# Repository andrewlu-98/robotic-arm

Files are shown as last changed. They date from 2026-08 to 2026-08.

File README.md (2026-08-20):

# 6-Axis Robotic Arm (Work in Progress)

An open-source, 6-DOF robotic arm featuring a custom mixed-architecture control board. The system offloads inverse kinematics (ROS 2 / Python) from a host laptop to an onboard Raspberry Pi Pico W analyzing encoder data and generating step signals.

---

## Hardware Overview

### Mechanical
The physical structure consists of a custom 3D printed robotic arm with one meter span. Joints are driven with Nema stepper motors through gear ratios and pulleys, controlling rotation and movement of arm. Motors are to be guided through sensor inputs (limit switches, MT6701) and controlled via Nema Stepper Motors and precise gear ratios.
<p align="center">
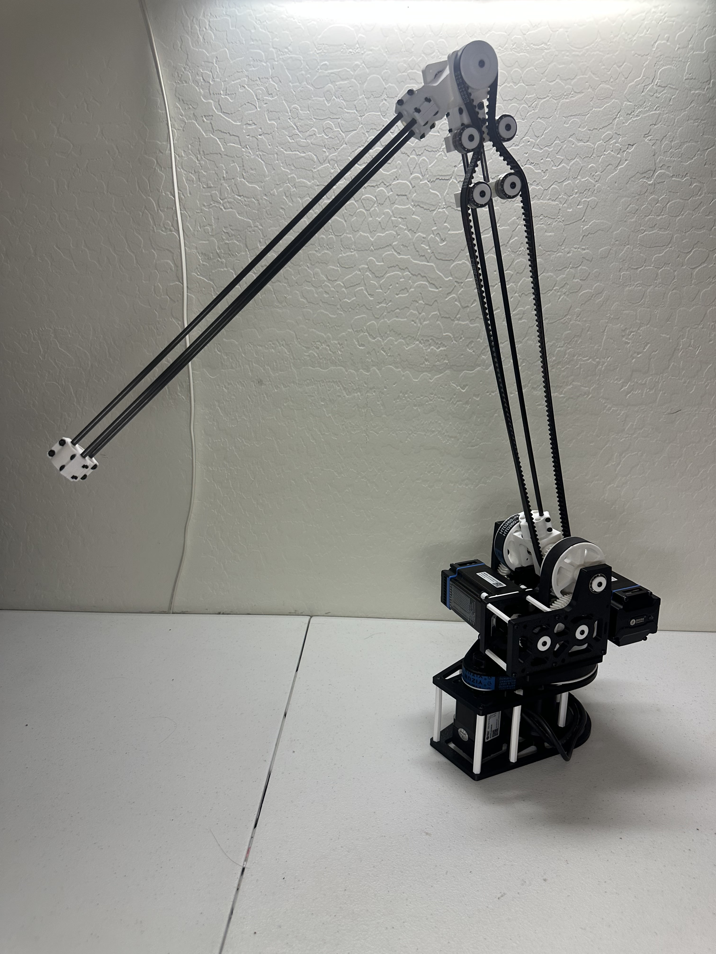
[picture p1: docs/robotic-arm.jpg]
Physical Arm Structure
  
</p>

### Electrical
Electronics consist of a power supply unit (connected to a wall outlet) sent to a PCB that actively controls the robotic arm through signals to the stepper motors and data from encoders and limit switches mounted near the stepper motors on the physical arm.
<p align="center">
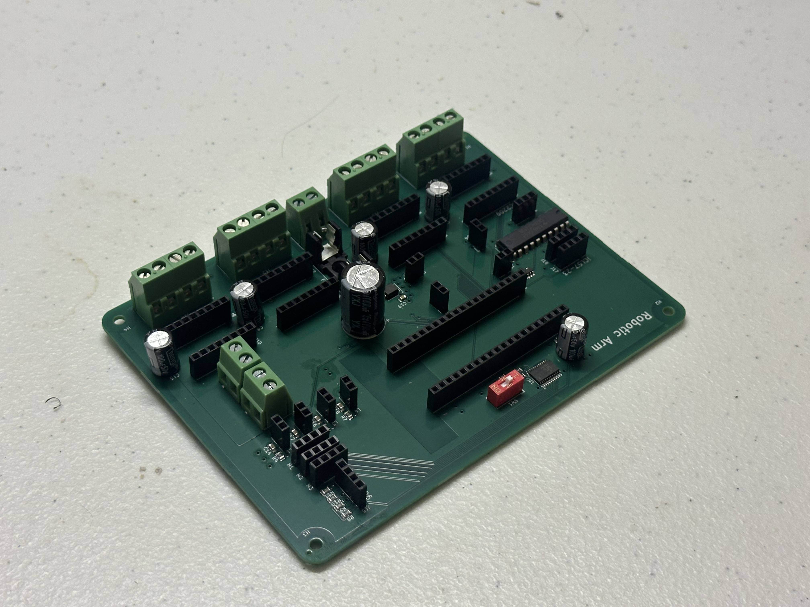
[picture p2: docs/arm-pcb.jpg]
Assembled PCB
  
</p>

The printed circuit board handles logic shifting via 74HCT245, limit switch & encoder monitoring, and I2C multiplexing. It houses pin headers for reusability of all boards in case of PCB failure. The board has thermal reliefs on 24V power pours, decoupling, and pull-up resistors for limit switch activation.
<p align="center">
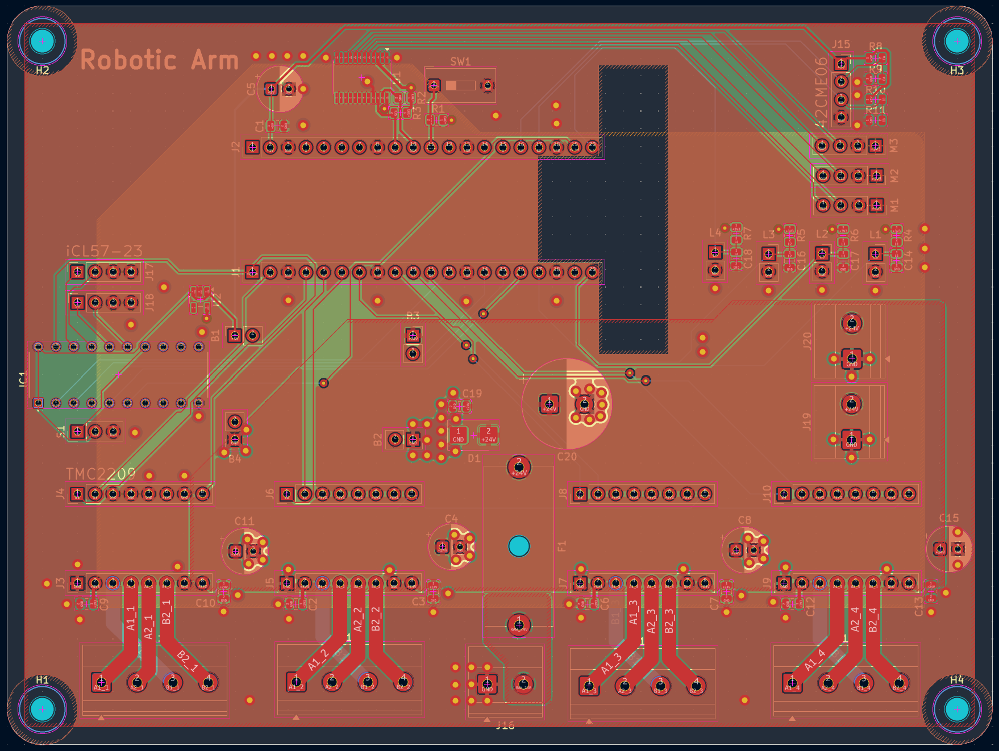
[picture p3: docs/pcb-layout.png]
PCB Layout
  
</p>

---

## System Architecture

### Hardware Stack
*   **Microcontroller:** Raspberry Pi Pico W (RP2040)
*   **Power:** Mean Well LRS-200-24 (24V, 8.8A), DFR0831 Buck Converter (24V to 5V logic)
*   **Actuators:** 
    *   3x STEPPERONLINE Short Body NEMA 17 (Driven via A4988)
    *   1x Leadshine 42CME06 Closed-Loop (Driven via TMC2209)
    *   2x Leadshine iCL57-23 (Integrated Drivers)
*   **Feedback:** MT6701 Magnetic Encoders (I2C) & Leadshine Quadrature Encoders

### Software Stack (In Progress)
*   **Host (Laptop):** ROS 2, Python, MoveIt 2 (Inverse Kinematics, Trajectory Planning, URDF/Xacro modeling).
*   **Firmware (Pico W):** C++ (Pico SDK). 
    *   **Core 0:** Serial communication (micro-ROS/Custom protocol) & Emergency Stop hardware interrupts.
    *   **Core 1:** PID closed-loop feedback processing.
    *   **PIO:** Mathematically precise step/direction pulse generation for 6 axes.

---

## Development Roadmap

- [x] Mechanical Design and Manufacturing
- [x] PCB Design and Manufacturing
- [x] Finalize BOM and Sourcing
- [x] **[Current]** ROS 2 URDF, RViz2, and Gazebo simulation
- [ ] C++ Firmware: Step generation, and analyzing encoder data
- [ ] Communication between laptop and Pico (micro-ROS)
- [ ] Full integration of mechanical, electrical, and software components

---

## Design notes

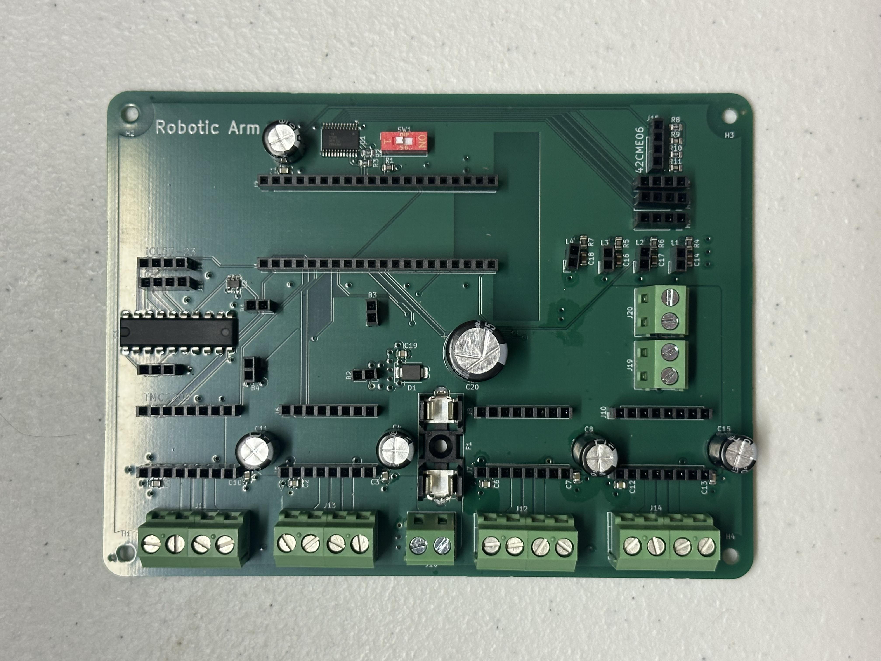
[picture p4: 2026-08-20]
docs/arm-pcb-top.jpg

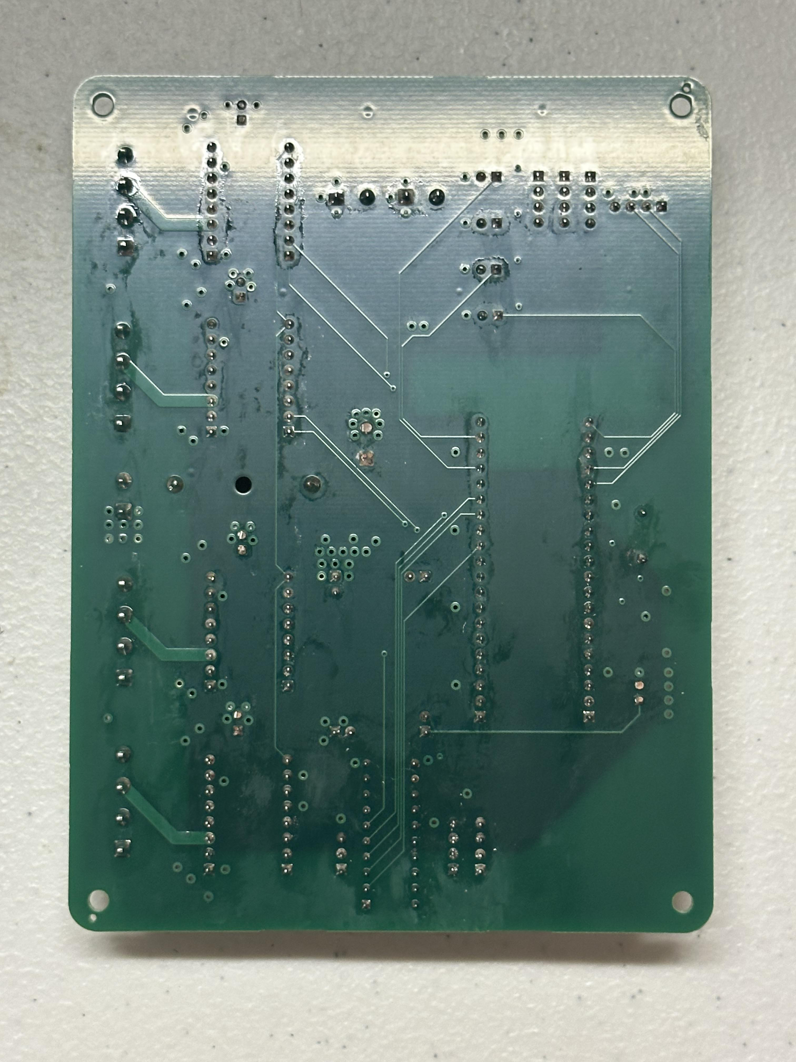
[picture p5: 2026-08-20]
docs/arm-pcb-bottom.jpg

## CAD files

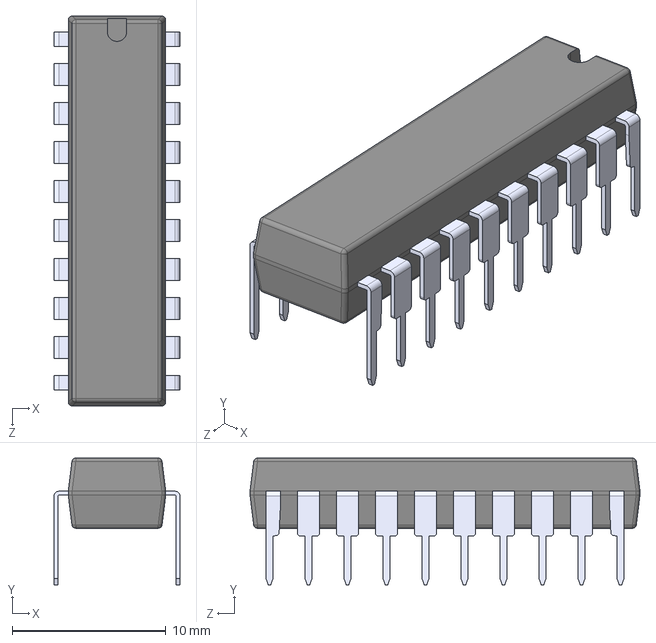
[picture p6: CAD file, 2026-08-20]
hardware/pcb/robotic_arm_steps/SN74HCT245N.step
8.19 x 8.26 x 25.4 mm

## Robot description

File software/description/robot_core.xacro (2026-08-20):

<?xml version="1.0"?>
<robot xmlns:xacro="http://www.ros.org/wiki/xacro" >

    <xacro:include filename="inertial_macros.xacro"/>

    <material name="white">
        <color rgba="1 1 1 1" />
    </material>

    <material name="gray">
        <color rgba="0.7 0.7 0.7 1"/>
    </material>

    <material name="orange">
        <color rgba="1 0.3 0.1 1" />
    </material>

    <material name="blue">
        <color rgba="0.2 0.2 1 1" />
    </material>

    <material name="black">
        <color rgba="0 0 0 1" />
    </material>

    <link name="world"/>

    <joint name="base_joint" type="fixed">
        <parent link="world"/>
        <child link="base"/>
        <origin xyz="0 0 0"/>
    </joint>

    <link name="base">
        <visual>
            <origin xyz="0 0 0.1"/>
            <geometry>
                <box size="0.2 0.2 0.2"/>
            </geometry>
            <material name="gray"/>
        </visual>
        <collision>
            <origin xyz="0 0 0.1"/>
            <geometry>
                <box size="0.2 0.2 0.2"/>
            </geometry>
        </collision>
    </link>

    <joint name="axis1_joint" type="revolute">
        <parent link="base"/>
        <child link="axis1"/>
        <origin xyz="0 0 0.2"/>
        <axis xyz="0 0 1"/>
        <limit lower="-3.15" upper="3.15" effort="100" velocity="1.0"/>
    </joint>

    <link name="axis1">
        <visual>
            <origin xyz="0 0 0.1"/>
            <geometry>
                <cylinder radius="0.1" length="0.2"/>
            </geometry>
            <material name="white"/>
        </visual>
        <collision>
            <origin xyz="0 0 0.1"/>
            <geometry>
                <cylinder radius="0.1" length="0.2"/>
            </geometry>
        </collision>
        <xacro:inertial_cylinder mass="0.1" length="0.04" radius="0.05">
            <origin xyz="0 0 0" rpy="0 0 0"/>
        </xacro:inertial_cylinder>
    </link>

    <joint name="axis2_joint" type="revolute">
        <parent link="axis1"/>
        <child link="axis2"/>
        <origin xyz="0 0 0.2"/>
        <axis xyz="0 1 0"/>
        <limit lower="-1.57" upper="1.57" effort="100" velocity="1.0"/>
    </joint>

    <link name="axis2">
        <visual>
            <origin xyz="0 0 0.45"/>
            <geometry>
                <cylinder radius="0.05" length="0.9"/>
            </geometry>
            <material name="blue"/>
        </visual>
        <collision>
            <origin xyz="0 0 0.45"/>
            <geometry>
                <cylinder radius="0.05" length="0.9"/>
            </geometry>
        </collision>
        <xacro:inertial_cylinder mass="0.1" length="0.04" radius="0.05">
            <origin xyz="0 0 0" rpy="0 0 0"/>
        </xacro:inertial_cylinder>
    </link>

    <joint name="axis3_joint" type="revolute">
        <parent link="axis2"/>
        <child link="axis3"/>
        <origin xyz="0 0 0.9"/>
        <axis xyz="0 1 0"/>
        <limit lower="-3" upper="3" effort="100" velocity="1.0"/>
    </joint>

    <link name="axis3">
        <visual>
            <origin xyz="0 0 0"/>
            <geometry>
                <cylinder radius="0.04" length="0.05"/>
            </geometry>
            <material name="orange"/>
        </visual>
        <collision>
            <origin xyz="0 0 0"/>
            <geometry>
                <cylinder radius="0.04" length="0.05"/>
            </geometry>
        </collision>
        <xacro:inertial_cylinder mass="0.1" length="0.04" radius="0.05">
            <origin xyz="0 0 0" rpy="0 0 0"/>
        </xacro:inertial_cylinder>
    </link>

    <joint name="axis4_joint" type="revolute">
        <parent link="axis3"/>
        <child link="axis4"/>
        <origin xyz="0 0 0"/>
        <axis xyz="0 0 1"/>
        <limit lower="-3.15" upper="3.15" effort="100" velocity="1.0"/>
    </joint>

    <link name="axis4">
        <visual>
            <origin xyz="0 0 0.5"/>
            <geometry>
                <cylinder radius="0.05" length="1"/>
            </geometry>
            <material name="white"/>
        </visual>
        <collision>
            <origin xyz="0 0 0.5"/>
            <geometry>
                <cylinder radius="0.05" length="1"/>
            </geometry>
        </collision>
        <xacro:inertial_cylinder mass="0.1" length="0.04" radius="0.05">
            <origin xyz="0 0 0" rpy="0 0 0"/>
        </xacro:inertial_cylinder>
    </link>

</robot>

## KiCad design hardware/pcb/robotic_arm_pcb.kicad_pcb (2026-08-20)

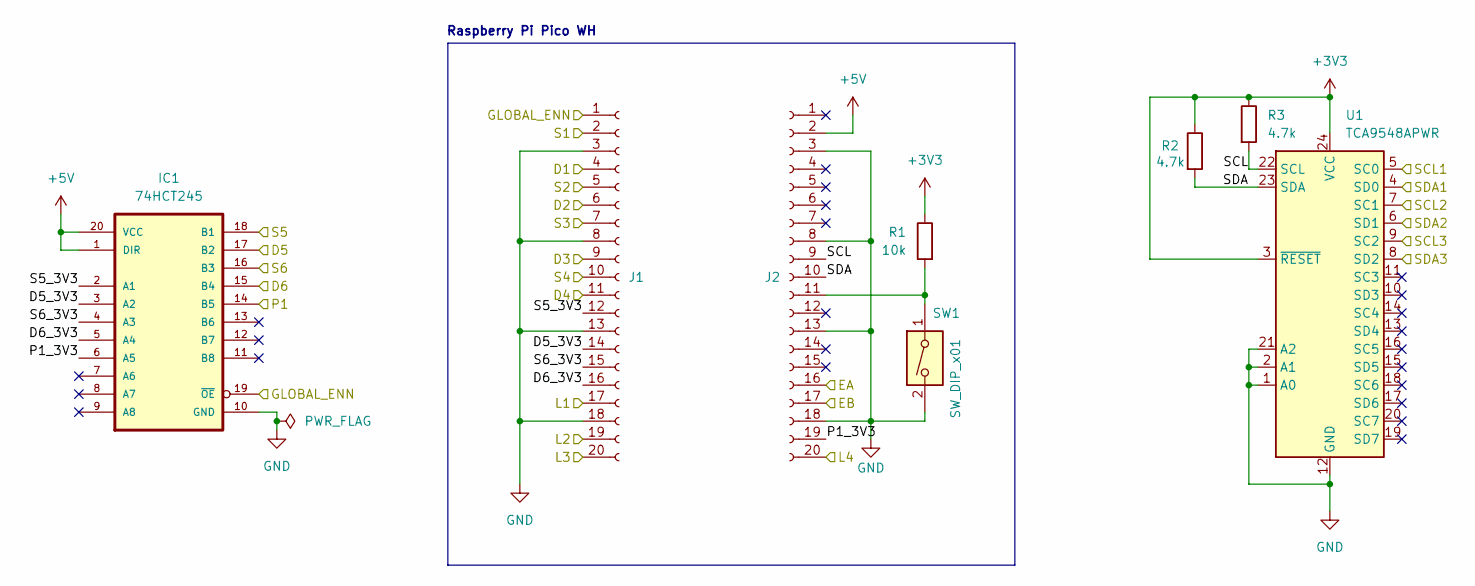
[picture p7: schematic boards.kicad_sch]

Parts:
IC1: 74HCT245; MODULE_SN74HCT245N; LCSC C133640
J1, J2: Conn_01x20_Socket; PinSocket_1x20_P2.54mm_Vertical; LCSC C2905423
R1: 10k; R_0805_2012Metric; LCSC C17414
R2, R3: 4.7k; R_0805_2012Metric; LCSC C441984
SW1: SW_DIP_x01; SW_DIP_SPSTx01_Slide_9.78x4.72mm_W7.62mm_P2.54mm; LCSC C501524
U1: TCA9548APWR; TSSOP-24_4.4x7.8mm_P0.65mm; LCSC C130026

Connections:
+3V3: R1.1, R2.1, R3.1, U1.3 (~RESET), U1.24 (VCC); also elsewhere on the board
+5V: IC1.1 (DIR), IC1.20 (VCC), J2.2; also elsewhere on the board
/Boards/D1: J1.4; also elsewhere on the board
/Boards/D2: J1.6; also elsewhere on the board
/Boards/D3: J1.9; also elsewhere on the board
/Boards/D4: J1.11; also elsewhere on the board
/Boards/D5: IC1.17 (B2); also elsewhere on the board
/Boards/D5_3V3: IC1.3 (A2), J1.14
/Boards/D6: IC1.15 (B4); also elsewhere on the board
/Boards/D6_3V3: IC1.5 (A4), J1.16
/Boards/EA: J2.16; also elsewhere on the board
/Boards/EB: J2.17; also elsewhere on the board
/Boards/GLOBAL_ENN: IC1.19 (~OE), J1.1; also elsewhere on the board
/Boards/L1: J1.17; also elsewhere on the board
/Boards/L2: J1.19; also elsewhere on the board
/Boards/L3: J1.20; also elsewhere on the board
/Boards/L4: J2.20; also elsewhere on the board
/Boards/P1: IC1.14 (B5); also elsewhere on the board
/Boards/P1_3V3: IC1.6 (A5), J2.19
/Boards/S1: J1.2; also elsewhere on the board
/Boards/S2: J1.5; also elsewhere on the board
/Boards/S3: J1.7; also elsewhere on the board
/Boards/S4: J1.10; also elsewhere on the board
/Boards/S5: IC1.18 (B1); also elsewhere on the board
/Boards/S5_3V3: IC1.2 (A1), J1.12
/Boards/S6: IC1.16 (B3); also elsewhere on the board
/Boards/S6_3V3: IC1.4 (A3), J1.15
/Boards/SCL: J2.9, R3.2, U1.22 (SCL)
/Boards/SCL1: U1.5 (SC0); also elsewhere on the board
/Boards/SCL2: U1.7 (SC1); also elsewhere on the board
/Boards/SCL3: U1.9 (SC2); also elsewhere on the board
/Boards/SDA: J2.10, R2.2, U1.23 (SDA)
/Boards/SDA1: U1.4 (SD0); also elsewhere on the board
/Boards/SDA2: U1.6 (SD1); also elsewhere on the board
/Boards/SDA3: U1.8 (SD2); also elsewhere on the board
GND: IC1.10 (GND), J1.3, J1.8, J1.13, J1.18, J2.3, J2.8, J2.13, J2.18, SW1.2, U1.1 (A0), U1.2 (A1), U1.12 (GND), U1.21 (A2); also elsewhere on the board
unnamed: J2.11, R1.2, SW1.1

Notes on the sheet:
Raspberry Pi Pico WH

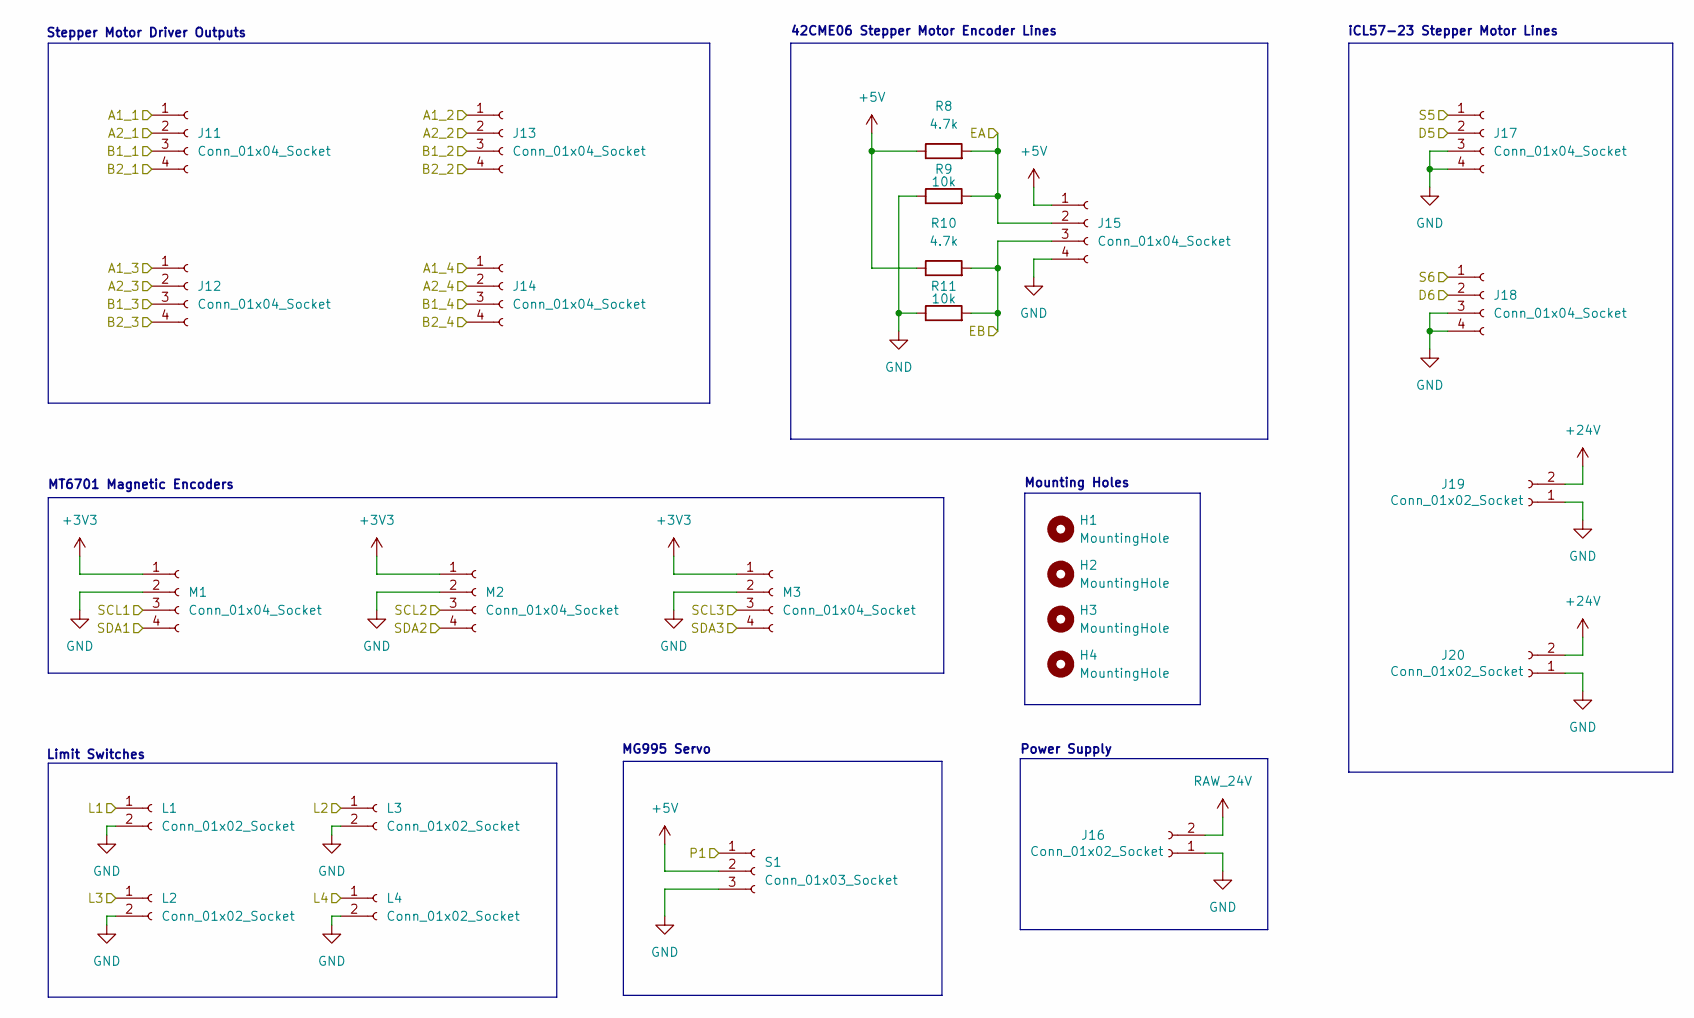
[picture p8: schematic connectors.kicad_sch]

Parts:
H1, H2, H3, H4: MountingHole; MountingHole_3.2mm_M3
J11, J12, J13, J14: Conn_01x04_Socket; TerminalBlock_Phoenix_MKDS-1,5-4-5.08_1x04_P5.08mm_Horizont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; LCSC C90087
J15, J17, J18: Conn_01x04_Socket; PinSocket_1x04_P2.54mm_Vertical; LCSC C2718488
J16, J19, J20: Conn_01x02_Socket; TerminalBlock_Phoenix_MKDS-1,5-2-5.08_1x02_P5.08mm_Horizont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; LCSC C474950
L1, L2, L3, L4: Conn_01x02_Socket; PinSocket_1x02_P2.54mm_Vertical; LCSC C49661
M1, M2, M3: Conn_01x04_Socket; PinSocket_1x04_P2.54mm_Vertical; LCSC C2718488
R8, R10: 4.7k; R_0805_2012Metric; LCSC C441984
R9, R11: 10k; R_0805_2012Metric; LCSC C17414
S1: Conn_01x03_Socket; PinSocket_1x03_P2.54mm_Vertical; LCSC C146243

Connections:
+3V3: M1.1, M2.1, M3.1; also elsewhere on the board
+5V: J15.1, R8.1, R10.1, S1.2; also elsewhere on the board
+24V: J19.2, J20.2; also elsewhere on the board
/Boards/D5: J17.2; also elsewhere on the board
/Boards/D6: J18.2; also elsewhere on the board
/Boards/EA: J15.2, R8.2, R9.2; also elsewhere on the board
/Boards/EB: J15.3, R10.2, R11.2; also elsewhere on the board
/Boards/L1: L1.1; also elsewhere on the board
/Boards/L2: L3.1; also elsewhere on the board
/Boards/L3: L2.1; also elsewhere on the board
/Boards/L4: L4.1; also elsewhere on the board
/Boards/P1: S1.1; also elsewhere on the board
/Boards/S5: J17.1; also elsewhere on the board
/Boards/S6: J18.1; also elsewhere on the board
/Boards/SCL1: M1.3; also elsewhere on the board
/Boards/SCL2: M2.3; also elsewhere on the board
/Boards/SCL3: M3.3; also elsewhere on the board
/Boards/SDA1: M1.4; also elsewhere on the board
/Boards/SDA2: M2.4; also elsewhere on the board
/Boards/SDA3: M3.4; also elsewhere on the board
/Connectors/A1_1: J11.1; also elsewhere on the board
/Connectors/A1_2: J13.1; also elsewhere on the board
/Connectors/A1_3: J12.1; also elsewhere on the board
/Connectors/A1_4: J14.1; also elsewhere on the board
/Connectors/A2_1: J11.2; also elsewhere on the board
/Connectors/A2_2: J13.2; also elsewhere on the board
/Connectors/A2_3: J12.2; also elsewhere on the board
/Connectors/A2_4: J14.2; also elsewhere on the board
/Connectors/B1_1: J11.3; also elsewhere on the board
/Connectors/B1_2: J13.3; also elsewhere on the board
/Connectors/B1_3: J12.3; also elsewhere on the board
/Connectors/B1_4: J14.3; also elsewhere on the board
/Connectors/B2_1: J11.4; also elsewhere on the board
/Connectors/B2_2: J13.4; also elsewhere on the board
/Connectors/B2_3: J12.4; also elsewhere on the board
/Connectors/B2_4: J14.4; also elsewhere on the board
GND: J15.4, J16.1, J17.3, J17.4, J18.3, J18.4, J19.1, J20.1, L1.2, L2.2, L3.2, L4.2, M1.2, M2.2, M3.2, R9.1, R11.1, S1.3; also elsewhere on the board
RAW_24V: J16.2; also elsewhere on the board

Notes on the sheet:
Stepper Motor Driver Outputs
Limit Switches
42CME06 Stepper Motor Encoder Lines
Power Supply
iCL57-23 Stepper Motor Lines
MG995 Servo
Mounting Holes
MT6701 Magnetic Encoders

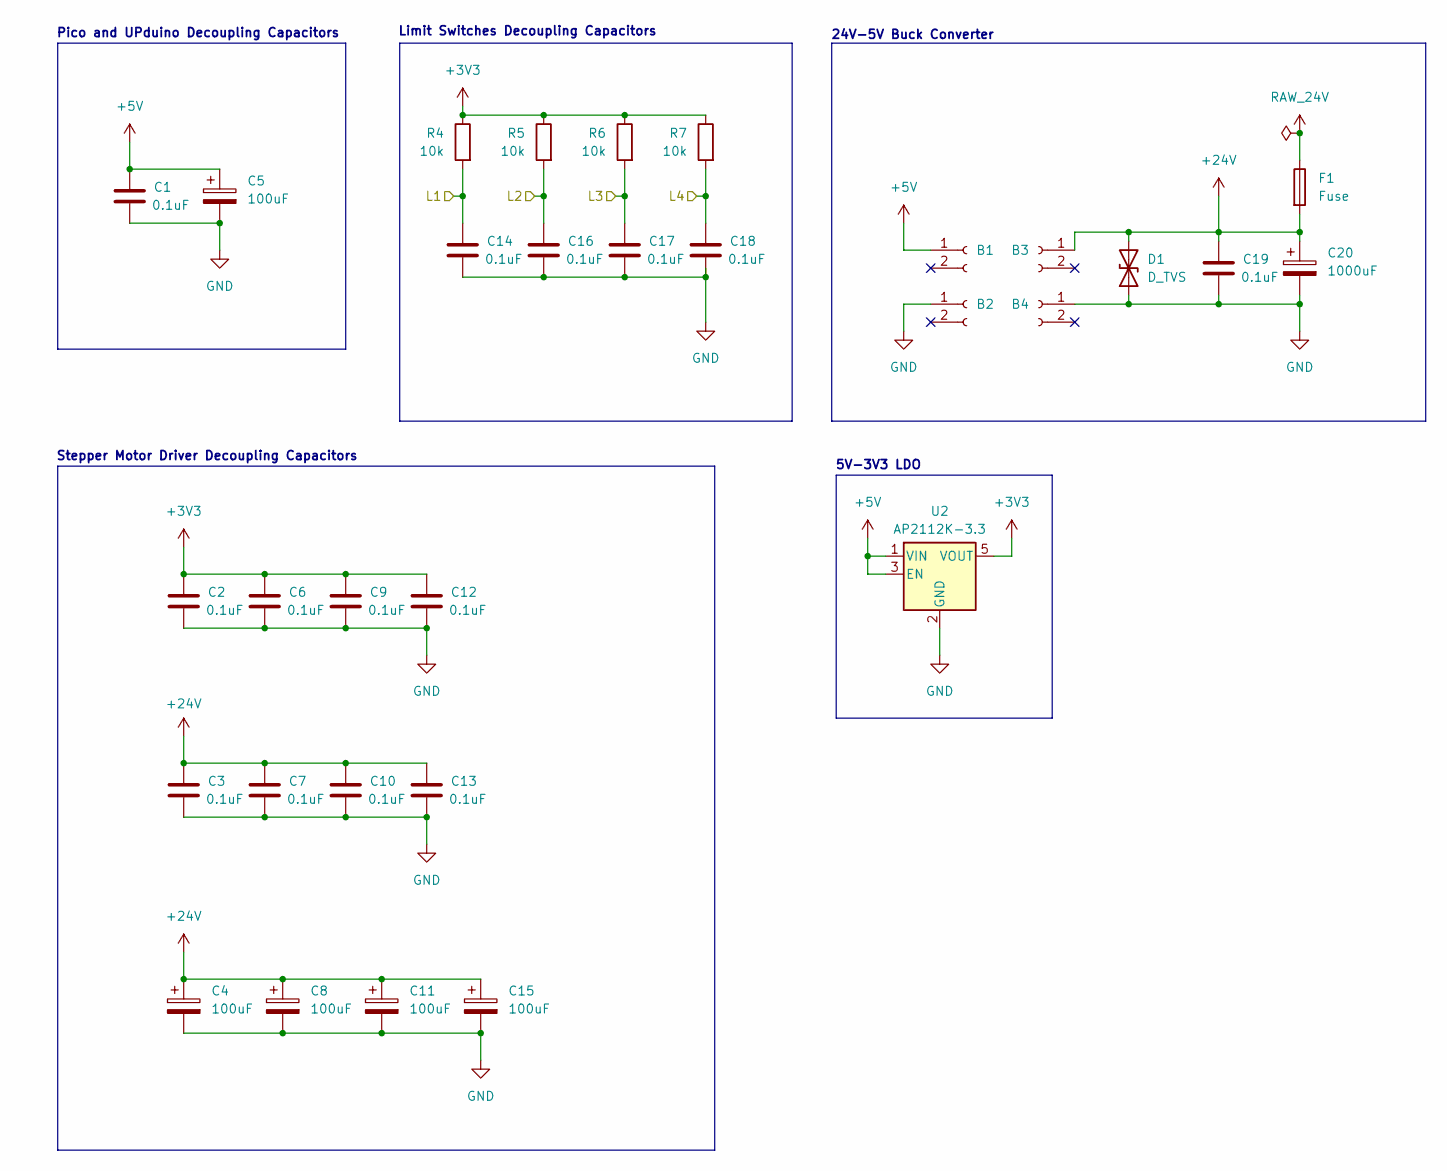
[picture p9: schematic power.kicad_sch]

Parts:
B1, B2, B3, B4: Conn_01x02_Socket; PinSocket_1x02_P2.54mm_Vertical; LCSC C49661
C1, C2, C3, C6, C7, C9, C10, C12, C13, C14, C16, C17, C18, C19: 0.1uF; C_0805_2012Metric; LCSC C49678
C4, C5, C8, C11, C15: 100uF; CP_Radial_D6.3mm_P2.50mm; LCSC C2749
C20: 1000uF; CP_Radial_D12.5mm_P5.00mm; LCSC C88743
D1: D_TVS; D_SMB; LCSC C123820
F1: Fuse; Fuseholder_Cylinder-5x20mm_Schurter_0031_8201_Horizontal_Op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; LCSC C3204125
R4, R5, R6, R7: 10k; R_0805_2012Metric; LCSC C17414
U2: AP2112K-3.3; SOT-23-5; LCSC C51118

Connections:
+3V3: C2.1, C6.1, C9.1, C12.1, R4.1, R5.1, R6.1, R7.1, U2.5 (VOUT); also elsewhere on the board
+5V: B1.1 (Pin_1_1), C1.1, C5.1, U2.1 (VIN), U2.3 (EN); also elsewhere on the board
+24V: B3.1 (Pin_1_1), C3.1, C4.1, C7.1, C8.1, C10.1, C11.1, C13.1, C15.1, C19.1, C20.1, D1.2 (A2), F1.2; also elsewhere on the board
/Boards/L1: C14.1, R4.2; also elsewhere on the board
/Boards/L2: C16.1, R5.2; also elsewhere on the board
/Boards/L3: C17.1, R6.2; also elsewhere on the board
/Boards/L4: C18.1, R7.2; also elsewhere on the board
GND: B2.1 (Pin_1_1), B4.1 (Pin_1_1), C1.2, C2.2, C3.2, C4.2, C5.2, C6.2, C7.2, C8.2, C9.2, C10.2, C11.2, C12.2, C13.2, C14.2, C15.2, C16.2, C17.2, C18.2, C19.2, C20.2, D1.1 (A1), U2.2 (GND); also elsewhere on the board
RAW_24V: F1.1; also elsewhere on the board

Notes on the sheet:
Pico and UPduino Decoupling Capacitors
5V-3V3 LDO
Limit Switches Decoupling Capacitors
Stepper Motor Driver Decoupling Capacitors
24V-5V Buck Converter

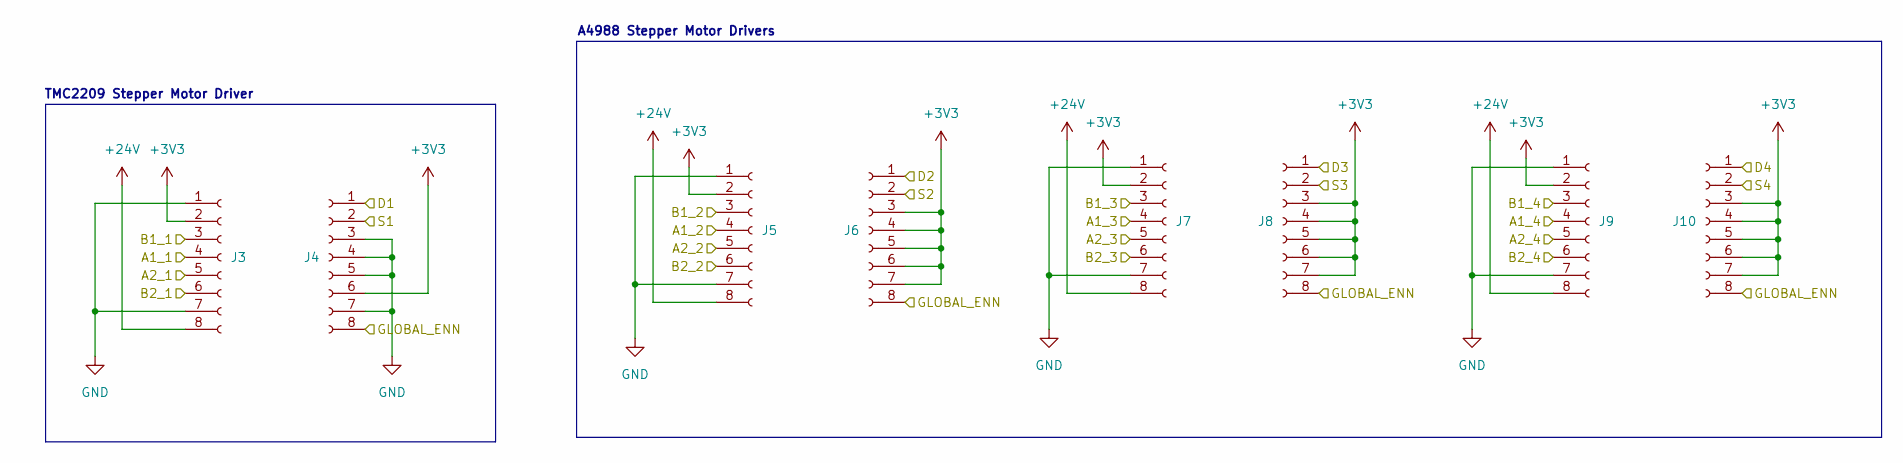
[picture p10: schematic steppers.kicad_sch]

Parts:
J3, J4, J5, J6, J7, J8, J9, J10: Conn_01x08_Socket; PinSocket_1x08_P2.54mm_Vertical; LCSC C27438

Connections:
+3V3: J3.2, J4.6, J5.2, J6.3, J6.4, J6.5, J6.6, J6.7, J7.2, J8.3, J8.4, J8.5, J8.6, J8.7, J9.2, J10.3, J10.4, J10.5, J10.6, J10.7; also elsewhere on the board
+24V: J3.8, J5.8, J7.8, J9.8; also elsewhere on the board
/Boards/D1: J4.1; also elsewhere on the board
/Boards/D2: J6.1; also elsewhere on the board
/Boards/D3: J8.1; also elsewhere on the board
/Boards/D4: J10.1; also elsewhere on the board
/Boards/GLOBAL_ENN: J4.8, J6.8, J8.8, J10.8; also elsewhere on the board
/Boards/S1: J4.2; also elsewhere on the board
/Boards/S2: J6.2; also elsewhere on the board
/Boards/S3: J8.2; also elsewhere on the board
/Boards/S4: J10.2; also elsewhere on the board
/Connectors/A1_1: J3.4; also elsewhere on the board
/Connectors/A1_2: J5.4; also elsewhere on the board
/Connectors/A1_3: J7.4; also elsewhere on the board
/Connectors/A1_4: J9.4; also elsewhere on the board
/Connectors/A2_1: J3.5; also elsewhere on the board
/Connectors/A2_2: J5.5; also elsewhere on the board
/Connectors/A2_3: J7.5; also elsewhere on the board
/Connectors/A2_4: J9.5; also elsewhere on the board
/Connectors/B1_1: J3.3; also elsewhere on the board
/Connectors/B1_2: J5.3; also elsewhere on the board
/Connectors/B1_3: J7.3; also elsewhere on the board
/Connectors/B1_4: J9.3; also elsewhere on the board
/Connectors/B2_1: J3.6; also elsewhere on the board
/Connectors/B2_2: J5.6; also elsewhere on the board
/Connectors/B2_3: J7.6; also elsewhere on the board
/Connectors/B2_4: J9.6; also elsewhere on the board
GND: J3.1, J3.7, J4.3, J4.4, J4.5, J4.7, J5.1, J5.7, J7.1, J7.7, J9.1, J9.7; also elsewhere on the board

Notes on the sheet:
TMC2209 Stepper Motor Driver
A4988 Stepper Motor Drivers

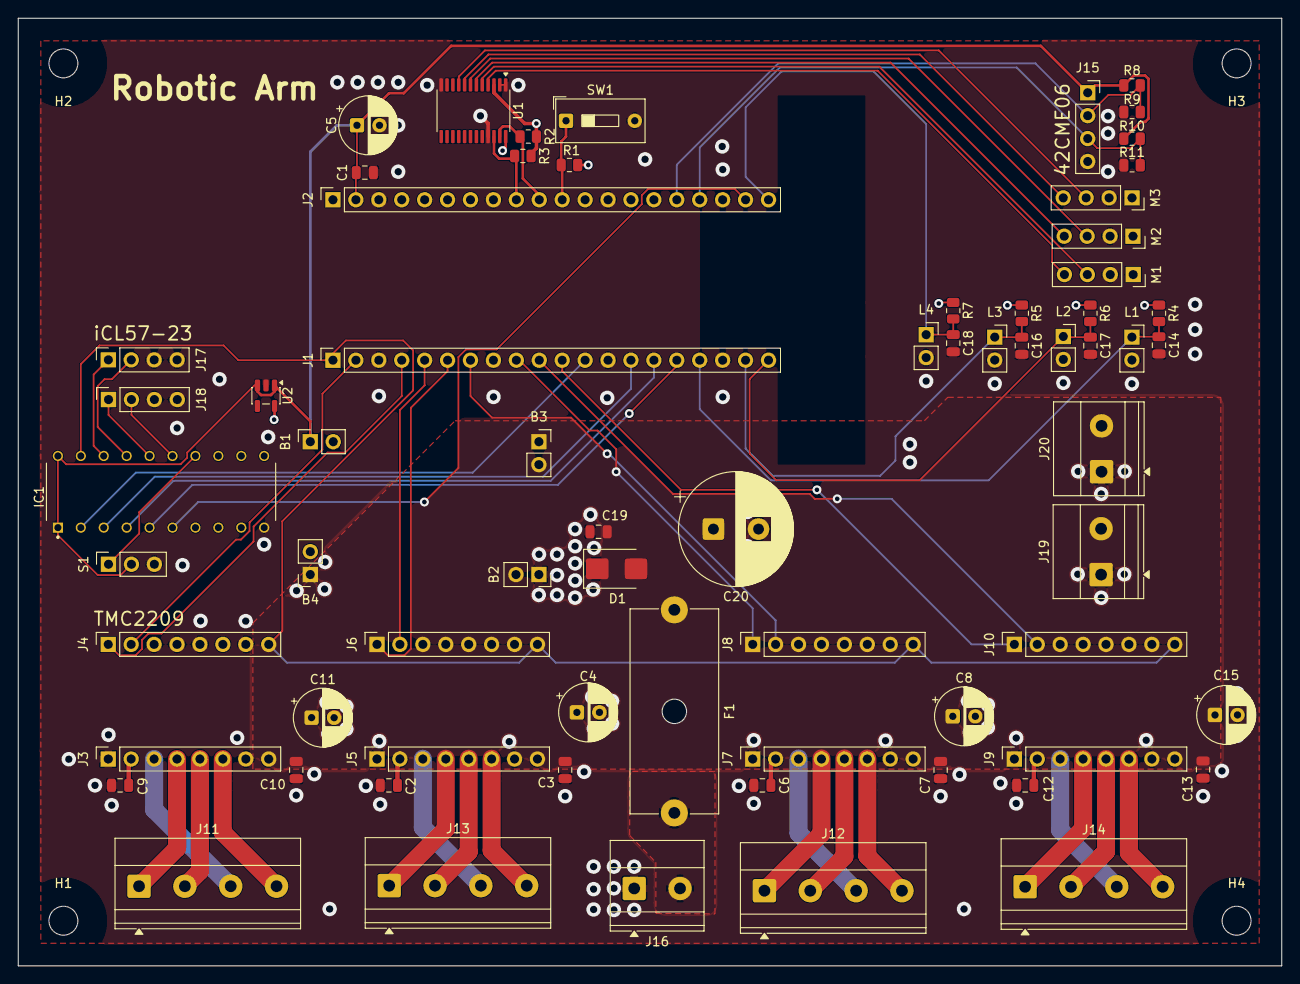
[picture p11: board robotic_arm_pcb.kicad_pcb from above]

Board: 4 copper layers, 140.0 x 105.0 mm, 73 parts (0 on the bottom side), 55 nets.

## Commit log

2026-08-03 Rename package from 'my_bot' to '6-axis-robotic-arm'
2026-08-03 Update package path for URDF file
2026-08-03 Rename project from 'my_bot' to '6-axis-robotic-arm'
2026-08-03 Rename package from '6-axis-robotic-arm' to 'robotic-arm'
2026-08-03 Update package name for URDF file processing
2026-08-03 Rename package from 'robotic-arm' to 'my_bot'
2026-08-03 Rename project from 'robotic-arm' to 'my_bot'
2026-08-03 Update package name from 'robotic-arm' to 'my_bot'
2026-08-20 simulation progress
    [arm_controllers.yaml, inertial_macros.xacro, robot.urdf.xacro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]
2026-08-20 readme update
    Updated sections for mechanical and electrical components, and added details about PCB layout.
